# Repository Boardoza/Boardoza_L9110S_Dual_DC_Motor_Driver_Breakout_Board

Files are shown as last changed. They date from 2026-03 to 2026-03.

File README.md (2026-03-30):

# Boardoza L9110S DC Motor Driver Breakout Board

The **Boardoza L9110S Breakout Board** is a dual-channel DC motor driver board built around the **L9110S motor driver IC.** It integrates a two-channel push-pull power amplifier in a compact breakout form, enabling bidirectional control of two DC motors through simple logic-level inputs.

The board supports **TTL / CMOS compatible control signals** and features low output saturation voltage along with integrated clamp diodes for inductive load protection. These characteristics make it suitable for low-voltage motor control in **embedded systems, including robotics platforms, educational development boards, small automation projects, and basic stepper motor driving applications** where direct GPIO-based motor control is required.

## [Click here to purchase!](https://www.ozdisan.com/p/arduino-sensorleri-ve-modulleri-613/ozd-arduino-l9110s-motor-driver-603181)
| Front Side | Back Side |
| :---: | :---: |
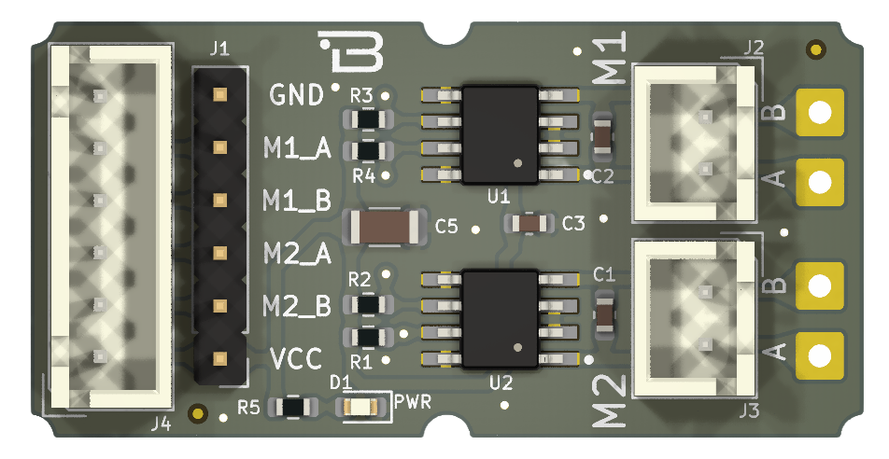
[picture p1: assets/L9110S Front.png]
Front
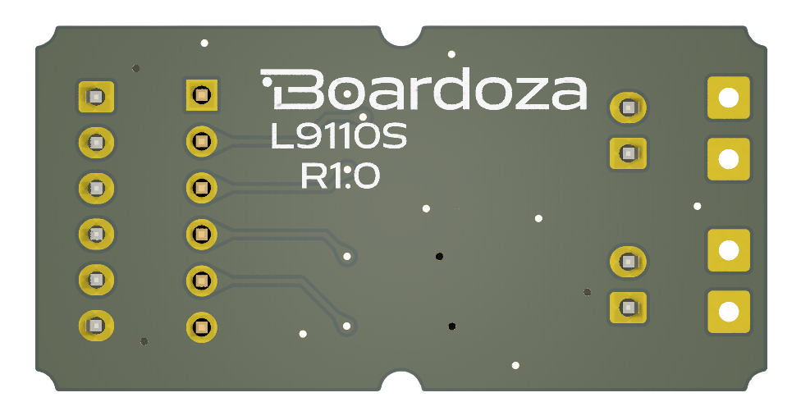
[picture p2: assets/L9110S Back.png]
Back
|  |  |

---

## Key Features

- **Dual-Channel DC Motor Driver:** Allows independent forward and reverse control of two DC motors.
- **Wide Operating Voltage Range:** Supports motor supply voltages from **2.5 V to 12 V**.
- **High Current Capability:** Delivers up to **750–800 mA continuous current per channel** with peak currents up to **1.5 -2 A**.
- **TTL / CMOS Compatible Inputs:** Can be directly interfaced with microcontrollers and CPUs without additional level shifting.
- **Low Output Saturation Voltage:** Improves efficiency and reduces power loss during motor operation.
- **Built-in Protection Diodes:** Integrated clamp diodes protect against reverse currents from inductive loads.
- **Low Quiescent Current:** Suitable for power-sensitive and battery-operated applications.

---

## Technical Specifications

**Model:** L9110S  
**Manufacturer:** Boardoza  
**Manufacturer IC:** Generic / Multiple vendors    
**Board Type:** Dual Channel DC Motor Driver Breakout Board  
**Input Voltage Range:** 2.5 V – 12 V  
**Output Current:** 750–800 mA continuous per channel  
**Peak Current:** Up to 1.5 A  
**Logic Level Compatibility:** TTL / CMOS  
**Motor Channels:** 2 (Independent control)  
**Supported Loads:** DC motors, stepper motors, relays, inductive loads  
**Power Input Type:** 2-pin 2.50 mm connector / 2.50 mm pin header  
**Control Interface:** Direct GPIO control (A/B inputs per channel)  
**Operating Temperature:** 0 °C to +80 °C  
**Board Dimensions:** 20 mm × 40 mm

---

## Electrical Characteristics

| Symbol | Parameter | Min  | Typical | Max  | Unit |
|:-----:|---|:----:|:---:|:----:|:----:|
| VCC | Supply Voltage | 2.5  | 6 | 12 | V |
| Idd | Quiescent Current | — | 0 | 2 | µA |
| Iin | Operating Current | 200  | 350 | 500  | µA |
| IC | Continuous Current | 750  | 800 | 850  | mA |
| IMax  | Peak Current | — | 1500 | 2000 | mA |

---

## Logical Control Table – Channel 1 (M1)

| M1_A | M1_B | A | B |
|:----:|:----:|:-:|:-:|
| H | L | H | L |
| L | H | L | H |
| L | L | L | L |
| H | H | L | L |

---

## Logical Control Table – Channel 2 (M2)

| M2_A | M2_B | A | B |
|:----:|:----:|:-:|:-:|
| H | L | H | L |
| L | H | L | H |
| L | L | L | L |
| H | H | L | L |

## Notes on Logic Levels

- **H (High):** Logic high level (TTL / CMOS compatible)
- **L (Low):** Logic low level  
- Motor direction is determined by the relative logic state of A and B inputs.
- Applying the same logic level to both inputs results in braking behavior.

---

## Board Pinout

### ( J1 ) Control & Power Connector

| Pin Number | Pin Name | Description |
| --- | --- | --- |
| 1 | VCC | Motor voltage positive input |
| 2 | M2_B | Channel 2 control input B |
| 3 | M2_A | Channel 2 control input A |
| 4 | M1_B | Channel 1 control input B |
| 5 | M1_A | Channel 1 control input A |
| 6 | GND | Ground |

### ( J4 ) Control & Power Connector (Parallel to J1)

| Pin Number | Pin Name | Description |
| --- | --- | --- |
| 1 | VCC | Motor voltage positive input |
| 2 | M2_B | Channel 2 control input B |
| 3 | M2_A | Channel 2 control input A |
| 4 | M1_B | Channel 1 control input B |
| 5 | M1_A | Channel 1 control input A |
| 6 | GND | Ground |

### ( J2 ) Motor Output – Channel 1 (M1)

| Pin Number | Pin Name | Description |
| --- | --- | --- |
| 1 | B | Motor output B (Channel 1) |
| 2 | A | Motor output A (Channel 1) |

### ( J3 ) Motor Output – Channel 2 (M2)

| Pin Number | Pin Name | Description |
| --- | --- | --- |
| 1 | B | Motor output B (Channel 2) |
| 2 | A | Motor output A (Channel 2) |

---

## Board Dimensions

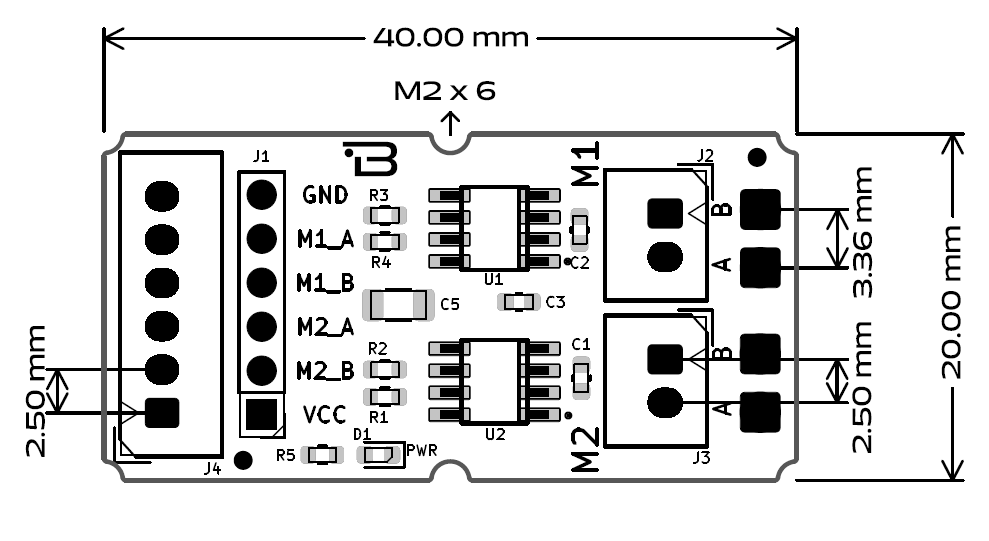
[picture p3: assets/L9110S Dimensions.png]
STM32 Black Pill Board Dimensions


---

## Step Files

[Boardoza L9110S.step](./assets/L9110S%20Step.step)

---

## Datasheet

[L9110S Datasheet](./assets/L9110S%20Datasheet.pdf)

---

## Version History

- v1.0 – Initial release

---

## Support

- For questions or technical support, please contact **support@boardoza.com**

---

## **License**

This repository contains both hardware and software components:

### **Hardware Design**

[][cc-by-sa]

All hardware design files are licensed under [Creative Commons Attribution-ShareAlike 4.0 International License][cc-by-sa].

[cc-by-sa]: http://creativecommons.org/licenses/by-sa/4.0/
[cc-by-sa-shield]: https://img.shields.io/badge/License-CC%20BY--SA%204.0-lightgrey.svg

### **Software/Firmware**

[][bsd]

All software and firmware are licensed under [BSD 3-Clause License][bsd].

[bsd]: https://opensource.org/licenses/BSD-3-Clause
[bsd-shield]: https://img.shields.io/badge/License-BSD%203--Clause-blue.svg

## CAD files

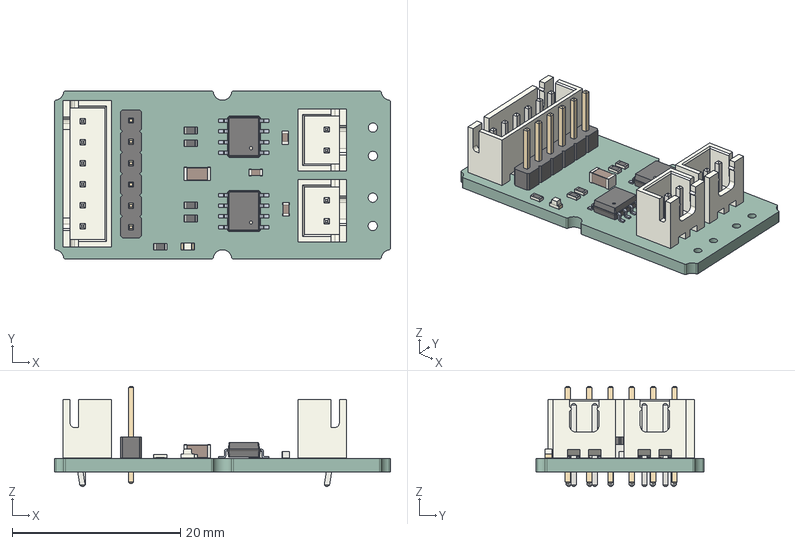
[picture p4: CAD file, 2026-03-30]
assets/L9110S Step.step
40.0 x 20.0 x 11.9 mm
JST_B6B_XH_A
JST_B2B_XH_A x 2
C_0603_1608Metric x 3
R_0603_1608Metric x 5
CQ assembly x 2
PinHeader_1x06_P254mm_Vertical
LED_0603_1608Metric
C_1206_3216Metric
_autosave-B-L9110S-Brk-01Mbr-R01_PCB

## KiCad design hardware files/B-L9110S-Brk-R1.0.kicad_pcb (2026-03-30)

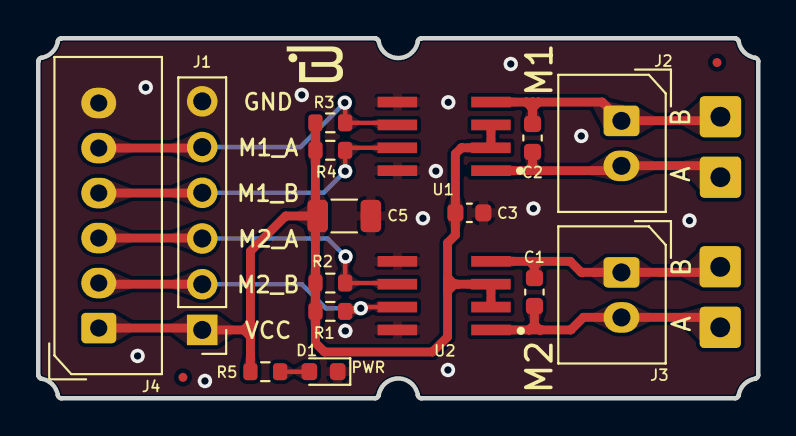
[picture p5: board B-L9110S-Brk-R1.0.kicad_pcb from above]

Board: 2 copper layers, 40.0 x 20.0 mm, 20 parts (0 on the bottom side), 11 nets.

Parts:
C1, C2, C3: 100nF; C_0603_1608Metric
C5: 10uF; C_1206_3216Metric
D1: LED RED; LED_0603_1608Metric
H1, H2, H3, H4: MountingHole_Pad; SolderWire-0.5sqmm_1x01_D0.9mm_OD2.3mm
J1: Conn_01x06_Pin; PinHeader_1x06_P2.54mm_Vertical
J2, J3: 2317-02; 2317-02S_1x02_P2.50mm_Vertical
J4: CONN_06FEMALE_LOCK; 2317-06S_1x06_P2.50mm_Vertical
R1, R2, R3, R4, R5: 10K; R_0603_1608Metric
U1: L9110
U2: B; L9110

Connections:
GND: C3.2, C5.2, D1.1 (K), J1.6, J4.6, U1.5 (GND@2), U1.8 (GND@1), U2.5 (GND@2), U2.8 (GND@1)
unnamed: D1.2 (A), R5.2
unnamed: J1.2, J4.2, R1.2, U2.7 (IB)
unnamed: J1.3, J4.3, R2.2, U2.6 (IA)
unnamed: J1.4, J4.4, R4.2, U1.7 (IB)
unnamed: J1.5, J4.5, R3.2, U1.6 (IA)
unnamed: C2.2, H4.1, J2.1, U1.4 (OB)
unnamed: C2.1, H3.1, J2.2, U1.1 (OA)
unnamed: C1.2, H2.1, J3.1, U2.4 (OB)
unnamed: C1.1, H1.1, J3.2, U2.1 (OA)
VCC: C3.1, C5.1, J1.1, J4.1, R1.1, R2.1, R3.1, R4.1, R5.1, U1.2 (VCC@1), U1.3 (VCC@2), U2.2 (VCC@1), U2.3 (VCC@2)

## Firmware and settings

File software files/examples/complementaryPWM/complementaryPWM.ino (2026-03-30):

#include <Arduino.h>
#include "driver/mcpwm.h"

// MCPWM Pins for Motor B
#define MOTOR_1_PWM   21   // M1A (PWM_B)
#define MOTOR_1_COMP  22   // M1B (Complementary PWM_B)

// MCPWM Pins for Motor A
#define MOTOR_2_PWM   18   // M2A (PWM_A)
#define MOTOR_2_COMP  19   // M2B (Complementary PWM_A)

// Dead Time (in nanoseconds)
#define DEAD_TIME_NS  1    // 10 = 1µs

// PWM Frequency
#define PWM_FREQ      200000  // 20kHz

/**
 * Sets the motor speed by updating the duty cycle.
 * duty_cycle: Range 0-255 (mapped to %0-%100)
 */
void set_motor_speed(mcpwm_unit_t unit, mcpwm_timer_t timer, float duty_cycle) {
  duty_cycle = constrain(duty_cycle, 0, 255);  
  mcpwm_set_duty(unit, timer, MCPWM_OPR_A, duty_cycle);
  mcpwm_set_duty_type(unit, timer, MCPWM_OPR_A, MCPWM_DUTY_MODE_0); // Complementary is automatically handled
}

void setup_mcpwm() {
  // MCPWM Configuration
  mcpwm_config_t pwm_config;
  pwm_config.frequency = PWM_FREQ;             // PWM Frequency
  pwm_config.cmpr_a = 50;                      // Initial duty cycle (%0)
  pwm_config.cmpr_b = 20;
  pwm_config.counter_mode = MCPWM_UP_COUNTER;  // Up-counter mode
  pwm_config.duty_mode = MCPWM_DUTY_MODE_1;    // Active HIGH duty cycle

  // MCPWM0 for Motor A
  mcpwm_init(MCPWM_UNIT_0, MCPWM_TIMER_0, &pwm_config);
  mcpwm_gpio_init(MCPWM_UNIT_0, MCPWM0A, MOTOR_2_PWM);    // PWM_A
  mcpwm_gpio_init(MCPWM_UNIT_0, MCPWM0B, MOTOR_2_COMP);   // Complementary PWM_A

  // MCPWM1 for Motor B
  mcpwm_init(MCPWM_UNIT_1, MCPWM_TIMER_1, &pwm_config);
  mcpwm_gpio_init(MCPWM_UNIT_1, MCPWM1A, MOTOR_1_PWM);    // PWM_B
  mcpwm_gpio_init(MCPWM_UNIT_1, MCPWM1B, MOTOR_1_COMP);   // Complementary PWM_B

  // Enable Dead Time (for both A and B channels)
  mcpwm_deadtime_enable(MCPWM_UNIT_0, MCPWM_TIMER_0, MCPWM_ACTIVE_HIGH_COMPLIMENT_MODE, DEAD_TIME_NS, DEAD_TIME_NS);
  mcpwm_deadtime_enable(MCPWM_UNIT_1, MCPWM_TIMER_1, MCPWM_ACTIVE_HIGH_COMPLIMENT_MODE, DEAD_TIME_NS, DEAD_TIME_NS);

  // Drive Motor A initial
  set_motor_speed(MCPWM_UNIT_0, MCPWM_TIMER_0, 50);
  
  // Drive Motor B initial
  set_motor_speed(MCPWM_UNIT_1, MCPWM_TIMER_1, 80);
}

void setup() {
  Serial.begin(115200);
  setup_mcpwm();
  Serial.println("Complementary PWM with ESP32 MCPWM Initialized");
}

uint8_t mot_speed = 50;
uint8_t direction = 0;

void loop() {
  // Check for Serial input for manual control
  if (Serial.available() >= 2) {
    int speedA = Serial.parseInt();  // Expected range: 0-100
    int speedB = Serial.parseInt();
    
    Serial.print("Motor A: %"); Serial.print(speedA);
    Serial.print(" | Motor B: %"); Serial.println(speedB);
  }

  delay(10);
  
  // Apply speed to both motors
  set_motor_speed(MCPWM_UNIT_0, MCPWM_TIMER_0, mot_speed);
  set_motor_speed(MCPWM_UNIT_1, MCPWM_TIMER_1, mot_speed);

  // Automatic Speed Ramping (Sweep) Logic
  if (!direction && mot_speed < 100) {
    mot_speed++; 
  } else {
    direction = 1;  
  }

  if (direction && mot_speed > 0) {
    mot_speed--;  
  } else {
    direction = 0;  
  }        
}

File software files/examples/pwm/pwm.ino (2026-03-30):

#include "Arduino.h"

// PWM Parameters
#define PWM_FREQ         1000      // PWM frequency: 1 kHz
#define PWM_RESOLUTION   8         // 8-bit resolution (range 0-255)

// LEDC channels for ESP32 (separate channel for each pin)
const int pwmChannel18 = 0; // Channel for Pin 18
const int pwmChannel21 = 1; // Channel for Pin 21
const int pwmChannel19 = 2; // Channel for Pin 19
const int pwmChannel22 = 3; // Channel for Pin 22

uint8_t mot_speed = 0;       // Motor speed (0-255)
uint8_t motor_direction = 0; // 0: Reverse, 1: Forward
bool rampUp = true;          // Is speed increasing?

void setup() {
  // PWM Configurations
  ledcSetup(pwmChannel18, PWM_FREQ, PWM_RESOLUTION);
  ledcAttachPin(18, pwmChannel18);
  
  ledcSetup(pwmChannel21, PWM_FREQ, PWM_RESOLUTION);
  ledcAttachPin(21, pwmChannel21);
  
  ledcSetup(pwmChannel19, PWM_FREQ, PWM_RESOLUTION);
  ledcAttachPin(19, pwmChannel19);
  
  ledcSetup(pwmChannel22, PWM_FREQ, PWM_RESOLUTION);
  ledcAttachPin(22, pwmChannel22);
}

void loop() {
  /* * Single motor control via pins 21 and 22.
   * According to the datasheet:
   * Forward (clockwise): IA HIGH, IB LOW
   * Reverse (counter-clockwise): IA LOW, IB HIGH
   * Logic: If motor_direction == 1, forward signal is applied.
   */
  if (motor_direction) { 
    // Forward direction: PWM active on Pin 18 and 21, Pin 19 and 22 are LOW
    ledcWrite(pwmChannel19, 0);
    ledcWrite(pwmChannel22, 0);
    ledcWrite(pwmChannel18, mot_speed);
    ledcWrite(pwmChannel21, mot_speed);
  } else { 
    // Reverse direction: PWM active on Pin 19 and 22, Pin 18 and 21 are LOW
    ledcWrite(pwmChannel18, 0);
    ledcWrite(pwmChannel21, 0);
    ledcWrite(pwmChannel19, mot_speed);
    ledcWrite(pwmChannel22, mot_speed);
  }

  /*
   * Speed Ramping Mechanism:
   * To prevent unwanted counter-rotation caused by motor inertia during 
   * direction changes, a short "dead time" (braking period) is added 
   * when the speed reaches zero.
   */
  if (rampUp) {
    if (mot_speed < 255) {
      mot_speed++;
    } else {
      // Switch to ramp down once maximum speed is reached
      rampUp = false;
    }
  } else { // Ramp down
    if (mot_speed > 0) {
      mot_speed--;
    } else {
      // Motor fully stopped: add dead time (braking duration)
      delay(100);  // Wait for 100 ms
      // Change direction after dead time
      motor_direction = (motor_direction == 1) ? 0 : 1;
      rampUp = true;
    }
  }
  
  delay(10);
}

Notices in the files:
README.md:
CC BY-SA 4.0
